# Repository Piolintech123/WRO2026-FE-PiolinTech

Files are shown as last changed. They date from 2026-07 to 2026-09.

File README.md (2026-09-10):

 <h1 align="center">Welcome to the PiolínTech Repository ꒰ঌ( •ө• )໒꒱ </h1>

<h3 align="center">
WRO Future Engineers 2026 · Panama
</h3>

<p align="center">
  PiolínTech WRO Future Engineers 2026 robot
<p align="center">
  <b>Meet Piolín — our autonomous EV3 vehicle developed for WRO Future Engineers 2026.</b>
</p>

<div align="center">

  <a href="https://youtube.com/@piolintech">
    
  </a>

  <a href="https://instagram.com/piolintech">
    
  </a>

  <a href="https://github.com/Piolintech123/WRO2026-FE-PiolinTech">
    
  </a>

</div>

<p align="center">
  
  
  
</p>

<p align="center">
  
  
  
  
  
</p>

---

## Project Summary

Piolín is the autonomous robotic vehicle developed by PiolínTech for the WRO
Future Engineers 2026 Self-Driving Car Challenge. The project is built around a
LEGO MINDSTORMS EV3 controller and a car-like vehicle architecture with rear
propulsion and Ackermann-style front steering.

Our objective is not only to make the robot complete the track. Piolín has been
developed as a complete electromechanical system in which mechanics, sensor
placement, control software, perception, testing, and calibration affect one
another. A mechanical adjustment can change sensor measurements, a sensor
relocation can require new calibration, and a software change is only useful
when the physical vehicle can reproduce the expected behavior consistently.

The current vehicle uses an EV3 Large Motor for propulsion and an EV3 Medium
Motor for steering. Two lateral EV3 Ultrasonic Sensors describe Piolín's
relationship with the track boundaries, while a downward-facing EV3 Color
Sensor detects physical Blue and Orange course landmarks. Sensor Port S1 is
round-specific: the Open Challenge uses an EV3 Gyro Sensor, while the Obstacle
Challenge uses Pixy2.1.

The current design intentionally avoids treating every available sensor as
something that must be installed at all times. The gyro and Pixy2.1 solve
different information problems, so they are used in different challenge
configurations and are not installed simultaneously.

This repository documents the complete development process behind Piolín. It
includes mechanical design, components, power distribution, sensor
architecture, autonomous software, obstacle avoidance, parking, calibration,
testing, failed ideas, engineering trade-offs, technical diagrams, 3D-printed
parts, source code, videos, photographic evidence, and the physical evolution
of the robot since 2025.

---

# General Project Index

This index is designed as the fastest path through the repository. Each section
provides direct access to the detailed documents behind the summaries in this
README, while the short descriptions explain what a judge or reader can expect
to find before opening a file.

## 1. Mobility & Mechanical Design

This section explains how Piolín moves, steers, transfers propulsion to the
rear wheels, and maintains a repeatable physical vehicle geometry. It also
documents why Ackermann steering was selected and how mechanical testing is
connected to software reliability.

- **[Mechanical Architecture](./docs/mobility_mechanical/01_mecharchitecture.md)** — Complete mechanical organization of Piolín and the relationship between the chassis, drivetrain, steering, sensors, and controller.
- **[Chassis Design](./docs/mobility_mechanical/02_chassis.md)** — Structural layout, reinforcement, packaging, physical constraints, and the reasoning behind the present chassis configuration.
- **[Robot Mobility](./docs/mobility_mechanical/03_RMobility.md)** — Vehicle movement, steering behavior, physical trajectory, and the interaction between propulsion and steering.
- **[Ackermann Steering](./docs/mobility_mechanical/04_steering.md)** — Steering geometry, steering angles, linkage behavior, mechanical limitations, and calibration.
- **[Drivetrain](./docs/mobility_mechanical/05_drivetrain.md)** — Motor A, rear propulsion, wheel transmission, mechanical coupling, and drivetrain decisions.
- **[Mechanical Testing](./docs/mobility_mechanical/06_testing.md)** — Physical testing process used to compare mechanical changes and identify repeatability problems.

<p align="center">
  <a href="./docs/mobility_mechanical/">
    
  </a>
</p>

## 2. Power & Sensor Architecture

This section explains how Piolín is powered, how every active sensor is
connected, what each sensor measures, and why the current sensor arrangement is
different between the Open and Obstacle Challenges.

- **[Power & Sensor Configuration](./docs/power_sensors/01_PowerSensorconfig.md)** — Current power and sensing architecture for both challenge configurations.
- **[Ultrasonic Sensor Design](./docs/power_sensors/02_USSensorD.md)** — The two lateral ultrasonic sensors, their physical positions, their geometric purpose, and the S2-left / S3-right convention.
- **[Color Sensor](./docs/power_sensors/03_color_sensor.md)** — S4 floor sensing, Blue and Orange detection, event confirmation, optical considerations, and calibration.
- **[Pixy2.1 Vision](./docs/power_sensors/04_pixycam.md)** — Current Pixy2.1 obstacle configuration, S1 connection, signatures, and its role in perception.
- **[Sensor Calibration](./docs/power_sensors/05_Calibration.md)** — Calibration workflow used after physical changes or environmental changes.
- **[Hardware Components](./docs/components/)** — Individual documentation for the EV3, motors, sensors, battery, power distribution, and additional parts.
- **[Technical Schemes](./schemes/README.md)** — EV3 reference, port mapping, current robot scheme, and Open configuration diagram.

<p align="center">
  <a href="./docs/power_sensors/">
    
  </a>
  <a href="./schemes/README.md">
    
  </a>
</p>

## 3. Software Architecture & Obstacle Strategy

This section contains the autonomous control logic behind Piolín. It covers
normal navigation, corner handling, color events, vision processing, obstacle
avoidance, recovery, control arbitration, software tuning, and parking.

- **[Software Architecture](./docs/software_obstacles_strategy/01_SWArchitecture.md)** — Overall software organization from sensing to final actuation.
- **[Navigation State Machine](./docs/software_obstacles_strategy/02_statemachine.md)** — How Piolín changes behavior according to its current physical situation.
- **[Wall Following & Geometry](./docs/software_obstacles_strategy/03_wallfollowing.md)** — Lateral navigation using the left and right Ultrasonic Sensors.
- **[Corner Handling](./docs/software_obstacles_strategy/04_cornerhandling.md)** — Why corners are handled differently from straight sections and how physical evidence is used.
- **[Obstacle Detection](./docs/software_obstacles_strategy/05_obstacledetec.md)** — How vision detections are validated and filtered before changing the robot trajectory.
- **[Obstacle Strategy](./docs/software_obstacles_strategy/06_obstaclestrateg.md)** — Red-right, Green-left passing behavior, target lifecycle, pass confirmation, and recovery.
- **[Software Tuning](./docs/software_obstacles_strategy/07_softwaretuning.md)** — How controller values and behaviors are adjusted through real track testing.
- **[Pixy Vision Processing](./docs/software_obstacles_strategy/08_CameraPXVision.md)** — Interpretation of signature, x, y, width, height, candidate relevance, and target selection.
- **[RGB Detection](./docs/software_obstacles_strategy/09_RGBdetection.md)** — Color classification logic used for floor sensing and experimental detection work.
- **[Color & Lap Counting](./docs/software_obstacles_strategy/10_color_and_lap_counting.md)** — Physical event processing, duplicate prevention, course progress, and lap counting.

### Parking Documentation

Parking is documented separately because it is a complete navigation problem
rather than a final timing command.

- **[Parking Overview](./docs/software_obstacles_strategy/parking/01_ParkingOverview.md)** — Complete parking objective and the information available to the robot.
- **[Parking Algorithm](./docs/software_obstacles_strategy/parking/02_ParkingAlgorithm.md)** — Approach, entry, alignment, final position, and stopping logic.
- **[Parking Geometry](./docs/software_obstacles_strategy/parking/03_ParkingGeom.md)** — Relationship between vehicle geometry and the physical parking maneuver.
- **[Parking Calibration](./docs/software_obstacles_strategy/parking/04_ParkingCalib.md)** — Parameters that must be validated on the real robot.
- **[Parking Testing](./docs/software_obstacles_strategy/parking/05_Parkingtesting.md)** — Repeatability tests and failure analysis for the parking maneuver.

### Published Source Code

- **[Round 1 — Open Code](./code/round1/ev3v1.py)** — Published Open Challenge EV3 program.
- **[Round 1 Code Explanation](./code/round1/r1_exp.md)** — Detailed explanation of the Round 1 program, its logic, and its limitations.
- **[Round 2 — Obstacle Code](./code/round2/ev3v1.py)** — Published Obstacle Challenge EV3 program.
- **[Round 2 Code Explanation](./code/round2/r2_exp.md)** — Detailed explanation of the Pixy2.1, ultrasonic, obstacle, and steering logic used in the published Round 2 version.

<p align="center">
  <a href="./docs/software_obstacles_strategy/">
    
  </a>
  <a href="./code/">
    
  </a>
</p>

## 4. Systems Thinking & Engineering Decisions

This section explains why the current robot looks and behaves the way it does.
It records alternatives, trade-offs, failure modes, risk analysis, design
constraints, and the engineering process used to decide whether a change should
remain in the robot.

- **[Engineering Process](./docs/systems_engineering/01_engineeringprocess.md)** — Observe, identify the first incorrect behavior, form a hypothesis, change one variable, test, compare, and document.
- **[Decision Log](./docs/systems_engineering/02_decisionlog.md)** — Major mechanical, sensing, and software decisions with their reasoning.
- **[Design Constraints](./docs/systems_engineering/03_designconstraints.md)** — Competition, mechanical, sensor, control, and practical constraints.
- **[Trade-offs](./docs/systems_engineering/04_tradeoffs.md)** — Comparison of alternative approaches and the reasons behind current choices.
- **[Risks & Mitigation](./docs/systems_engineering/05_risksandmitigation.md)** — Important failure conditions and how the design attempts to reduce their impact.
- **[What Didn't Work](./docs/systems_engineering/06_whatdidntwork.md)** — Rejected ideas, failed experiments, and lessons that affected later versions.
- **[Project Timeline](./t-gtku/timeline.md)** — Development history beginning in June 2025.
- **[Robot Evolution](./models/evolution/Phase1.md)** — Entry point to the documented physical and architectural evolution of Piolín.

<p align="center">
  <a href="./docs/systems_engineering/">
    
  </a>
  <a href="./t-gtku/timeline.md">
    
  </a>
</p>

## 5. Reproducibility & GitHub Quality

This section contains the information required to understand how Piolín is
assembled, wired, configured, calibrated, programmed, tested, and diagnosed.

- **[Reproducibility Overview](./docs/reproducibility/01_ReproducibilityOverview.md)** — Starting point for reproducing the present hardware and software configuration.
- **[Bill of Materials](./docs/reproducibility/02_BOM.pdf)** — Components required for the robot.
- **[Wiring Guide](./docs/reproducibility/03_wiring.md)** — Motor, sensor, and round-specific S1 connections.
- **[Electrical Schematics](./docs/reproducibility/04_elecschem.md)** — Electrical and port-reference diagrams.
- **[Software Setup](./docs/reproducibility/05_softwaresetup.md)** — Preparing the EV3 environment and transferring the competition programs.
- **[Calibration Guide](./docs/reproducibility/06_HowToCalibrate.md)** — Steering, ultrasonic, color, gyro, and Pixy calibration.
- **[Testing Protocol](./docs/reproducibility/07_TestingProtocol.md)** — How tests are repeated and compared.
- **[Troubleshooting](./docs/reproducibility/08_Troubleshooting.md)** — Diagnosing common mechanical, sensing, and software problems.
- **[3D Printing Files](./models/3dprint/)** — STL files and manufacturing documentation.
- **[Vehicle Photo Archive](./v-photos/README.md)** — Visual evidence of the robot from previous generations through V4.
- **[Videos](./videos/links.md)** — Autonomous track demonstrations and test footage.

<p align="center">
  <a href="./docs/reproducibility/">
    
  </a>
  <a href="./docs/reproducibility/02_BOM.pdf">
    
  </a>
</p>

---

# Watch Piolín

## Video Evidence

The fastest way to understand Piolín is to see the vehicle operating on the
physical track. Our videos provide direct evidence of autonomous behavior under
both competition configurations and complement the source code and technical
documents stored in this repository.

The Open Challenge demonstration shows Piolín operating with the Open-round
sensing configuration. The Obstacle Challenge demonstration shows the vehicle
operating with visual traffic-sign detection and obstacle navigation.

<p align="center">
  <a href="https://www.youtube.com/watch?v=JROB39Az-Ys">
    
  </a>
  <a href="https://youtu.be/Tlw_LM0b6WE">
    
  </a>
</p>

Additional demonstrations and testing material are available in
[videos/links.md](./videos/links.md).

---

# Meet the Team

## Team Overview

We are PiolínTech, a robotics team from Colegio Bilingüe de Panamá. Developing
Piolín has required collaboration across mechanical construction, programming,
sensor calibration, testing, documentation, failure analysis, and redesign.

Future Engineers has repeatedly shown us that many problems cannot be separated
into purely mechanical or purely software categories. A steering error may
originate from code, but it can also result from linkage geometry or mechanical
alignment. A sensor problem may originate from software thresholds, but it may
also come from mounting geometry, light conditions, or the surface being
observed.

For that reason, the team approaches Piolín as a complete system. The objective
during testing is not only to make the visible symptom disappear, but to
understand which subsystem caused the first incorrect behavior.

| Member | Information | Contact |
| :---: | :--- | :---: |
|  | **Sebastián Martínez**<br>Colegio Bilingüe de Panamá | [Instagram](https://www.instagram.com/sebastian.mvrl/) |
|  | **Mia Cantoral**<br>Colegio Bilingüe de Panamá | [Instagram](https://www.instagram.com/miaacnt) |
|  | **Christian Castrellón**<br>Colegio Bilingüe de Panamá | [Instagram](https://www.instagram.com/cj.chriss) |
| **Coach** | **Hanna Figueroa**<br>Colegio Bilingüe de Panamá | |

<p align="center">
  <a href="./t-gtku/officialpictureptech.md">
    
  </a>
  <a href="./t-gtku/funnypicture.md">
    
  </a>
  <a href="./t-gtku/timeline.md">
    
  </a>
</p>

---

# Meet Piolín

## Current Vehicle Overview

<p align="center">
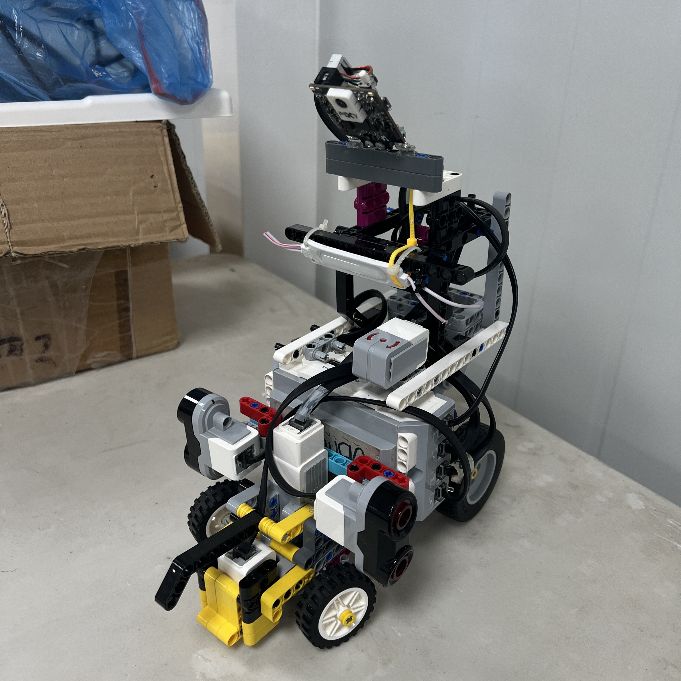
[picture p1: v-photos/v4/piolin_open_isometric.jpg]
Current Piolín V4 robot
  
</p>

The current V4 Piolín architecture is built around clearly defined subsystem
responsibilities. Motor A handles propulsion, Motor B controls Ackermann
steering, S2 and S3 observe lateral track geometry, and S4 detects physical
floor landmarks.

S1 is the only major sensor port that changes between challenges. During the
Open Challenge, S1 contains the EV3 Gyro Sensor. During the Obstacle Challenge,
the gyro is removed and Pixy2.1 is installed instead.

Piolín currently has a measured mass of 0.84 kg. Current practical physical
references are approximately 250 mm in overall length, approximately 119 mm
across the front assembly, approximately 105 mm across the rear assembly,
approximately 290 mm in height, and approximately 120 mm between the axles.

These physical references are treated as current measurements rather than
permanent CAD values. Mechanical changes can alter the final configuration, so
the robot is rechecked when a modification affects the competition envelope,
sensor location, or steering geometry.

## Current Hardware

| System | Current Configuration |
| --- | --- |
| **Controller** | LEGO MINDSTORMS EV3 |
| **Propulsion** | EV3 Large Motor — Port A |
| **Steering** | EV3 Medium Motor — Port B |
| **Steering Geometry** | Ackermann-style |
| **Drive Layout** | Rear propulsion |
| **Left Distance Sensor** | EV3 Ultrasonic — S2 |
| **Right Distance Sensor** | EV3 Ultrasonic — S3 |
| **Floor Sensor** | EV3 Color Sensor — S4 |
| **Open S1 Device** | EV3 Gyro Sensor |
| **Obstacle S1 Device** | Pixy2.1 |
| **Battery** | EV3 Rechargeable Battery 45501 |
| **Measured Mass** | **0.84 kg** |

---

## Two Challenges, One Core Platform

Piolín uses the same core mechanical vehicle for both competition challenges.
Keeping the drivetrain, steering system, controller, two lateral Ultrasonic
Sensors, and Color Sensor consistent reduces the number of variables that
change when moving from one challenge to the other.

The main round-specific difference is S1. During Open, Piolín needs independent
heading and rotation information, so the EV3 Gyro Sensor occupies S1. During
Obstacles, visual color-signature information is required, so the gyro is
removed and Pixy2.1 takes its place.

The gyro and Pixy2.1 are not installed simultaneously in the current
competition architecture.

| Port | Open Challenge | Obstacle Challenge |
| :---: | --- | --- |
| **A** | EV3 Large Motor — propulsion | EV3 Large Motor — propulsion |
| **B** | EV3 Medium Motor — steering | EV3 Medium Motor — steering |
| **S1** | EV3 Gyro Sensor | Pixy2.1 |
| **S2** | LEFT Ultrasonic Sensor | LEFT Ultrasonic Sensor |
| **S3** | RIGHT Ultrasonic Sensor | RIGHT Ultrasonic Sensor |
| **S4** | Downward Color Sensor | Downward Color Sensor |

<p align="center">
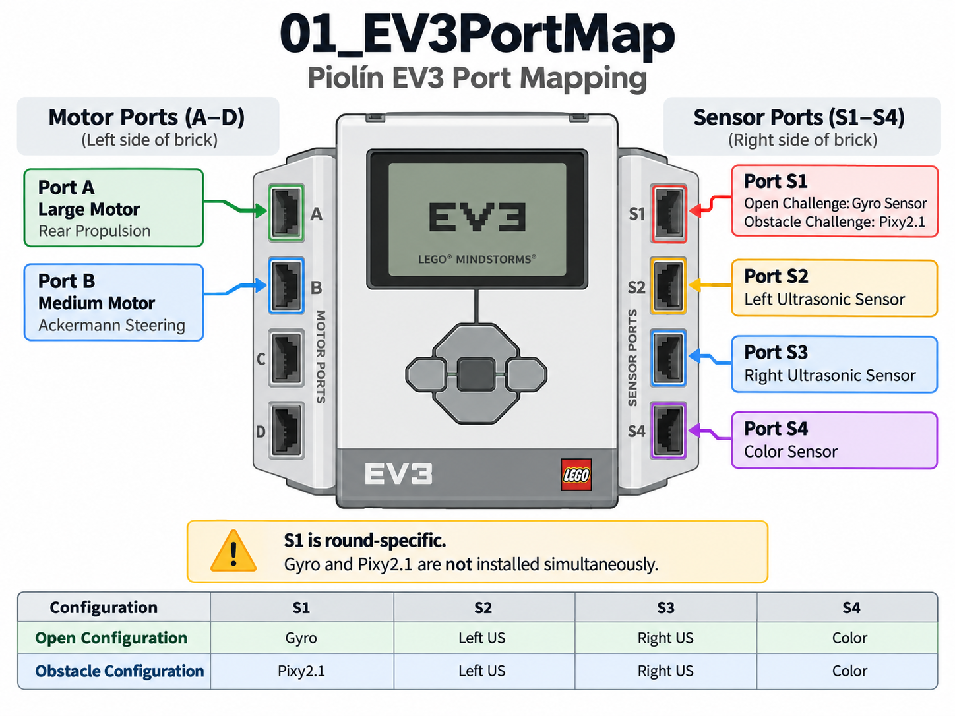
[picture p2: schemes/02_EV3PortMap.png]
Piolín EV3 Port Map
  
</p>

S2 remains physically left and S3 remains physically right in both rounds.
Their interpretation as an inner or outer sensor changes only according to the
course direction.

---

# Mobility & Mechanical Design

## Mechanical Overview

<p align="center">
  
</p>

Piolín uses a car-like architecture based on rear propulsion and
Ackermann-style front steering. Motor A drives the rear section of the vehicle,
while Motor B controls the steering mechanism at the front.

Unlike a differential-drive robot, Piolín cannot simply rotate by driving the
left and right sides at different speeds. Its path depends on the steering
angle of the front wheels and the forward or reverse motion generated by the
drivetrain.

This makes mechanical geometry part of the control problem. A different
steering angle, linkage position, wheel alignment, or chassis flex can change
the path produced by exactly the same software command.

The mechanical documentation therefore focuses not only on what pieces are
present, but also on how the physical arrangement affects autonomous behavior.

<p align="center">
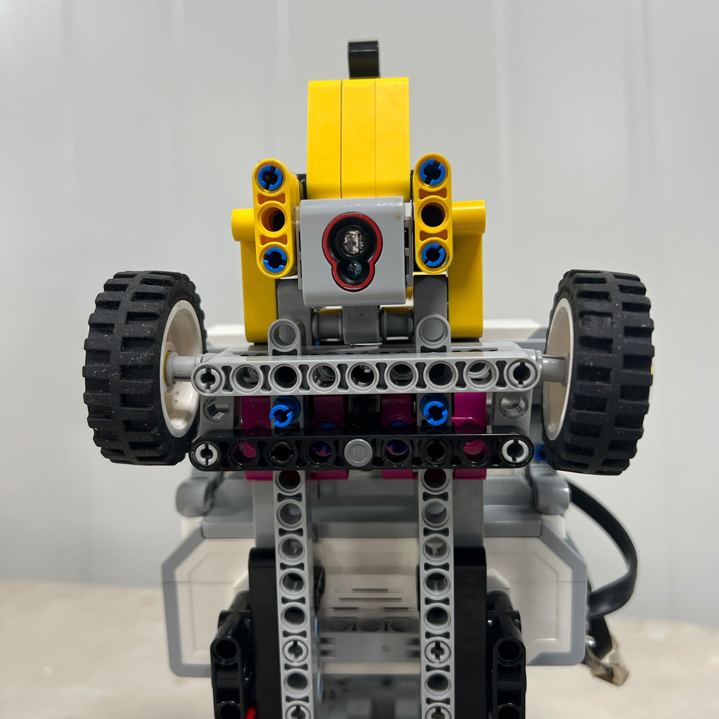
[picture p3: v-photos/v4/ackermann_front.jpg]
Piolín Ackermann steering
  
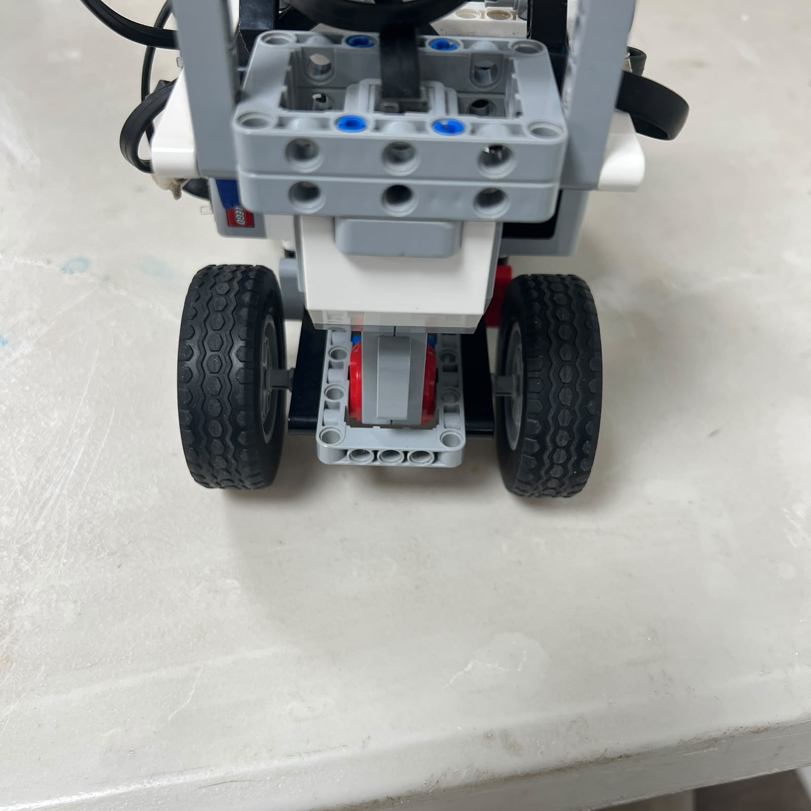
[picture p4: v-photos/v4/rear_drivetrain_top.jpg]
Piolín rear drivetrain
  
</p>

## Ackermann Steering

During a turn, the inner front wheel follows a smaller radius than the outer
front wheel. The two wheels should therefore not remain perfectly parallel
throughout the maneuver.

Ackermann steering provides a geometric relationship between the inner and
outer wheel angles so the wheel paths converge toward a common turning center.

The ideal relationship can be represented by:

$$
\cot(\delta_{outer})-\cot(\delta_{inner})=\frac{w}{L}
$$

where \(w\) represents the track width and \(L\) represents the wheelbase.

The equation provides a useful geometric model, but the real LEGO mechanism
still has physical tolerances. Joint clearance, tire deformation, steering
linkage geometry, Motor B positioning, mechanical stops, and assembly alignment
influence the actual vehicle trajectory.

For that reason, steering geometry is evaluated through photographs, angle
observations, repeated runs, and physical calibration rather than assuming that
the theoretical model alone predicts the complete motion.

<p align="center">
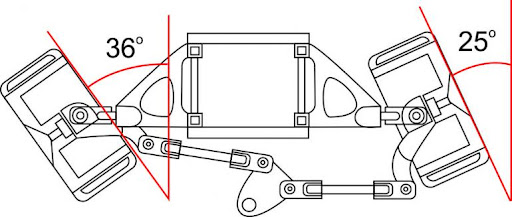
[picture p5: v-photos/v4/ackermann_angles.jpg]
Ackermann steering analysis
  
</p>

## Steering Motor

The EV3 Medium Motor on Port B is dedicated to steering. Using a separate motor
for the steering system allows the software to reason about vehicle speed and
steering angle as different control variables.

The steering motor is centered before autonomous testing so its encoder
reference corresponds as closely as possible to the straight-wheel position.

A steering command is useful only when the mechanical linkage responds
consistently. If the linkage is loose, asymmetric, or physically obstructed, a
correct Motor B target can still produce an incorrect path.

This is why steering calibration always has both a software and mechanical
component.

<p align="center">
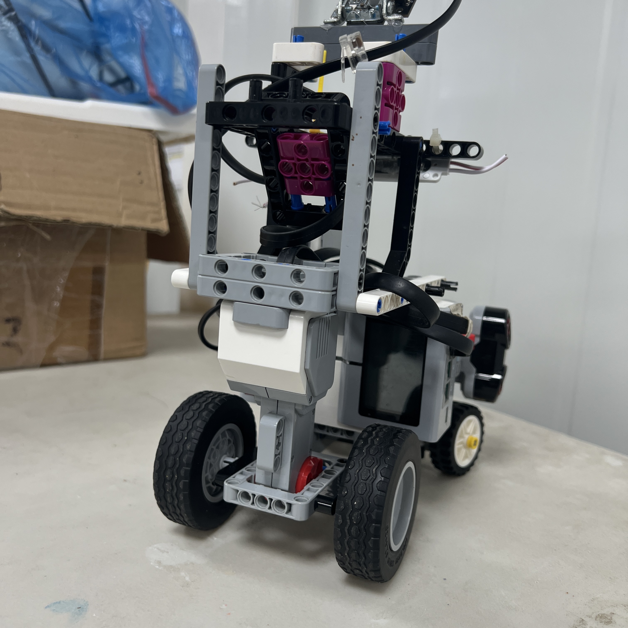
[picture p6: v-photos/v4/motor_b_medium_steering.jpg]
Motor B steering
  
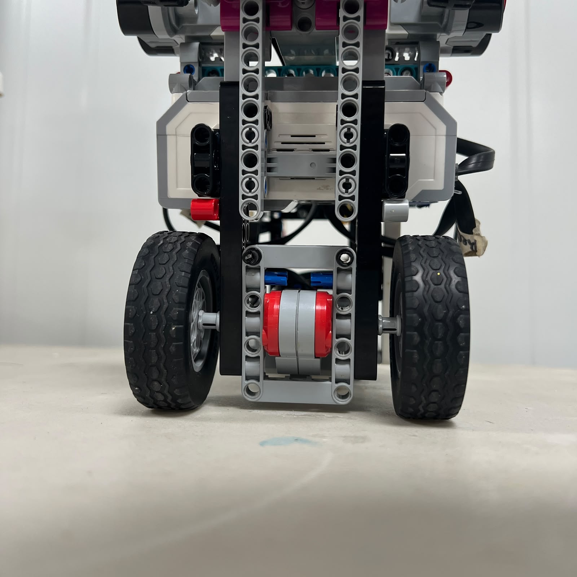
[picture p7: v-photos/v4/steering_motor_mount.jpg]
Steering motor mount
  
</p>

## Chassis Development

Piolín's chassis has changed repeatedly throughout development. Early versions
were useful for discovering how much space was required for the EV3, steering
mechanism, drivetrain, sensors, wiring, and later the vision system.

As the project matured, the chassis became more strongly connected to
navigation performance. A structural element that moves under load can affect
steering. A sensor mount that rotates slightly can change distance
measurements. A cable that interferes with steering can cause a software
symptom even though the controller is functioning correctly.

The current chassis therefore aims to maintain repeatable positions for the
main mechanical and sensing components while still remaining practical to
service and recalibrate.

The repository preserves previous versions because the transition from those
layouts to V4 provides evidence of the engineering process.

<p align="center">
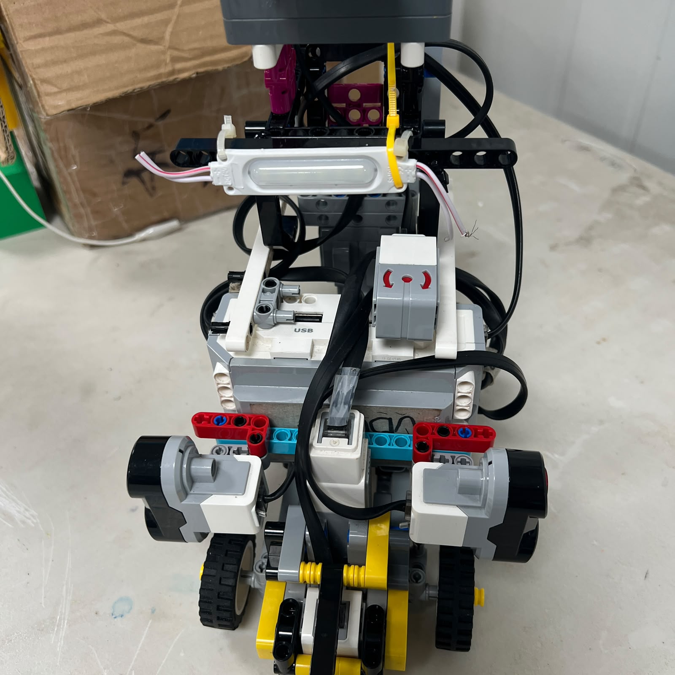
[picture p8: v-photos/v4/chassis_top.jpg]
Current chassis top view
  
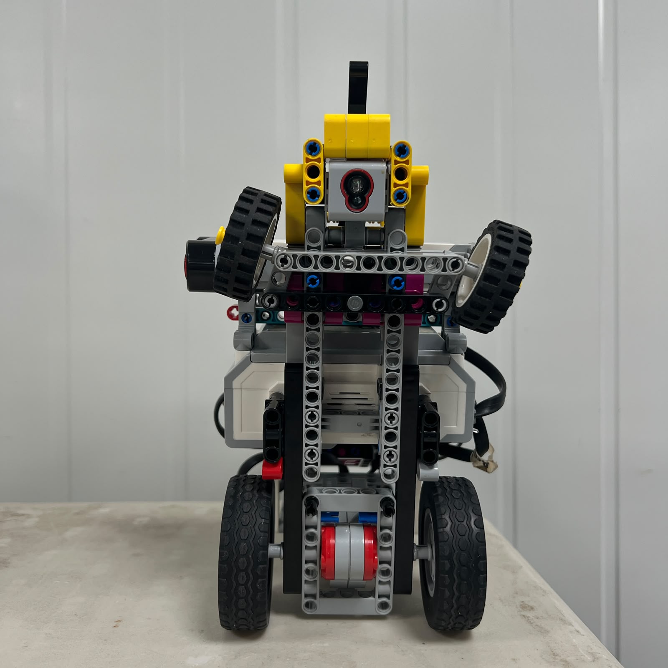
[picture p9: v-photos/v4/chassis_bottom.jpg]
Current chassis bottom view
  
</p>

## Rear Drivetrain

Motor A is an EV3 Large Motor dedicated to propulsion. Its role is mechanically
separate from Motor B, which means steering changes do not require differential
motor-speed control.

Keeping propulsion inside the EV3 ecosystem reduces wiring complexity and gives
the controller direct access to encoder information from the drive motor.

The drivetrain is evaluated as a complete path from motor output to wheel
motion. Mechanical losses, wheel grip, structural alignment, and the physical
load on the robot all influence how the vehicle accelerates and how
consistently it follows a requested path.

<p align="center">
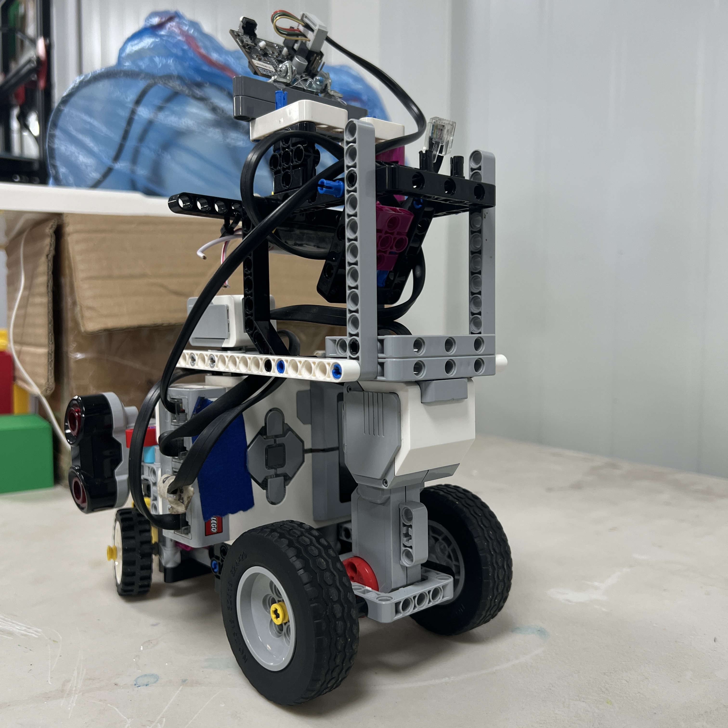
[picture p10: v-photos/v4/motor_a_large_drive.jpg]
EV3 Large Motor
  
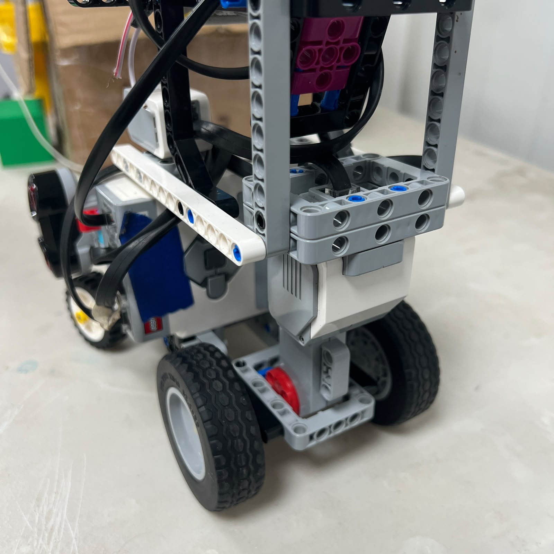
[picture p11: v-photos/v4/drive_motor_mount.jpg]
Drive motor mounting
  
</p>

## Torque and Dynamic Reasoning

Piolín currently has a measured mass of 0.84 kg. The drivetrain therefore has
to move the complete robot mass while overcoming rolling resistance and any
additional losses caused by wheel contact and drivetrain friction.

A simplified longitudinal force requirement can be represented as:

$$
F_t = ma + F_{resistance}
$$

and the corresponding wheel torque as:

$$
\tau = F_t r
$$

where \(m\) is vehicle mass, \(a\) is acceleration, \(F_{resistance}\)
represents resistive forces, and \(r\) is the effective radius of the driven
wheel.

These equations are used as engineering references rather than as claims of
guaranteed performance. Real track behavior depends on friction, tire
deformation, battery state, wheel alignment, and mechanical losses that are
difficult to represent perfectly in a simplified model.

<p align="center">
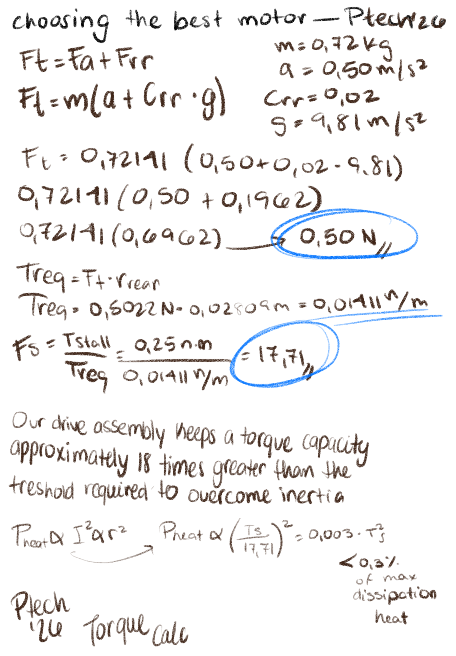
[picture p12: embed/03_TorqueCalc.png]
Piolín torque calculation
  
</p>

## Mechanical Testing Philosophy

Mechanical testing is performed with the same mindset used for software
testing. We try to isolate the first physical behavior that changes when a run
becomes unreliable.

If Piolín begins to drift, the first question is not automatically which
controller value should be changed. The team checks wheel alignment, steering
centering, sensor position, mechanical interference, and the condition of the
drivetrain before assuming that the problem originates in code.

This avoids compensating for a mechanical fault with increasingly aggressive
software corrections.

<p align="center">
  <a href="./docs/mobility_mechanical/01_mecharchitecture.md">
    
  </a>
  <a href="./docs/mobility_mechanical/04_steering.md">
    
  </a>
  <a href="./docs/mobility_mechanical/05_drivetrain.md">
    
  </a>
  <a href="./docs/mobility_mechanical/06_testing.md">
    
  </a>
</p>

---

# Power & Sensor Architecture

## Electrical and Sensing Overview

<p align="center">
  
</p>

Piolín is powered by the official LEGO MINDSTORMS EV3 Rechargeable DC Battery
45501. The EV3 Brick is the central controller and also provides the interfaces
used by the motors and active sensors.

The current competition architecture intentionally avoids unnecessary external
power and control layers. There is no Raspberry Pi, external propulsion
battery, custom H-bridge, or Arduino Nano in the current configuration.

Earlier experiments with additional electronics remain documented in the legacy
section because they influenced later engineering decisions, especially the
preference for simpler communication paths and fewer failure points.

<p align="center">
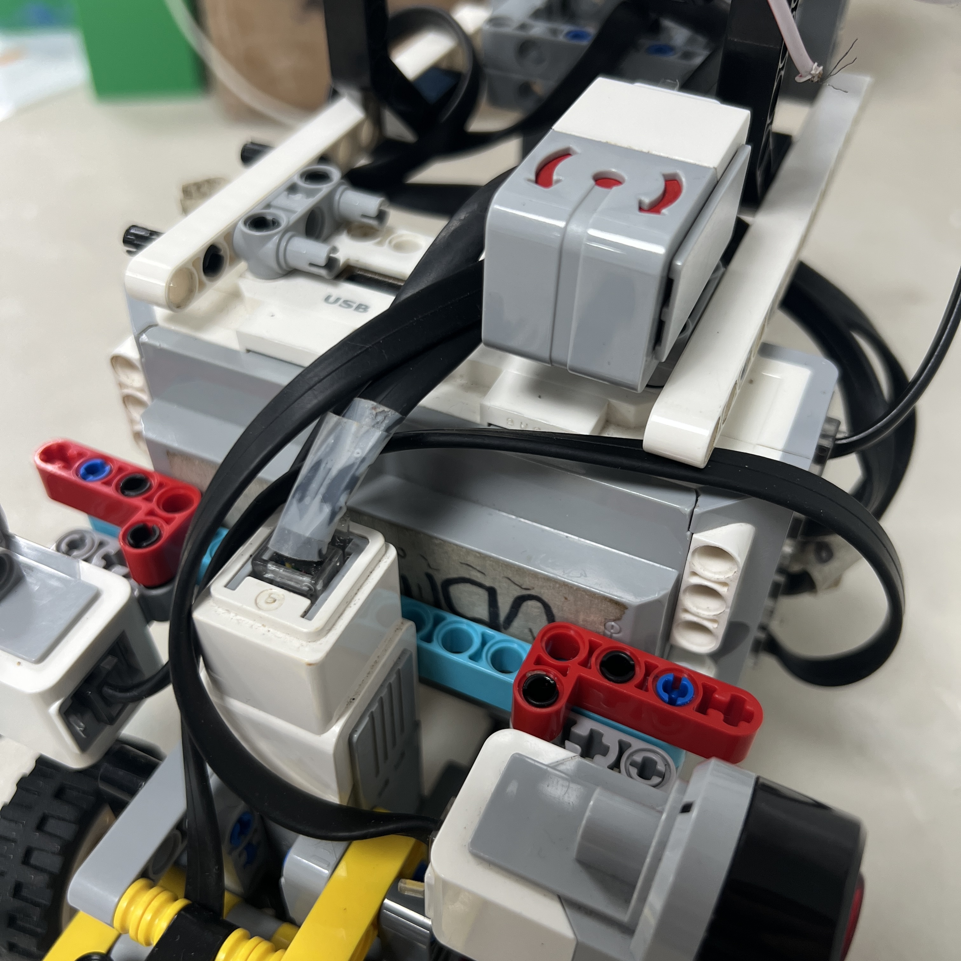
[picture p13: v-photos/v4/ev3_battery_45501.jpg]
EV3 Rechargeable Battery 45501
  
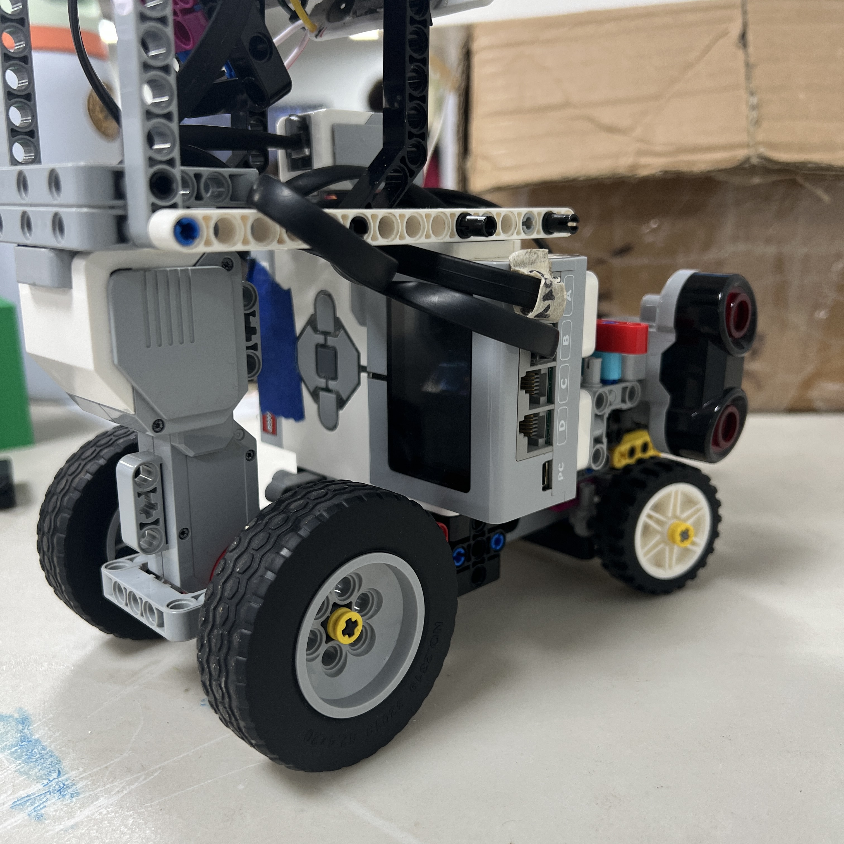
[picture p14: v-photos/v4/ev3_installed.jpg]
EV3 installed in Piolín
  
</p>

## EV3 Controller

The EV3 Brick is the central control unit in every current Piolín
configuration. It executes the navigation software, reads sensors, commands the
two motors, and provides the physical port structure that keeps the electrical
architecture organized.

The decision to remain centered around EV3 also improves reproducibility. The
motors, gyro, ultrasonic sensors, Color Sensor, and battery are all directly
associated with the same platform.

Pixy2.1 is the principal non-LEGO sensing device in the current obstacle
configuration.

<p align="center">
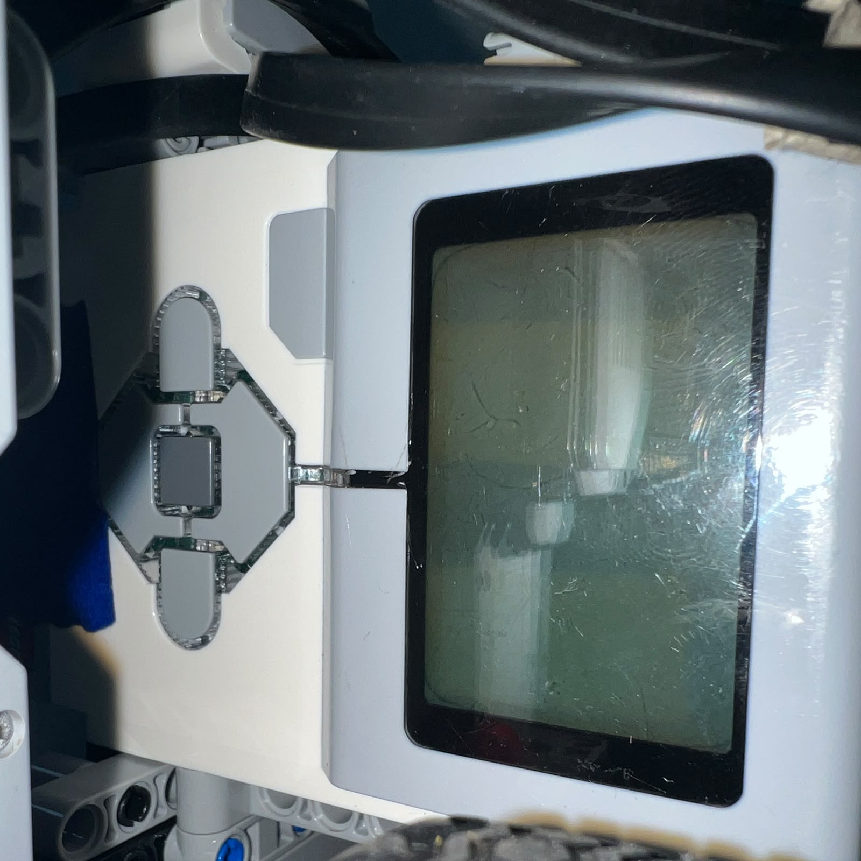
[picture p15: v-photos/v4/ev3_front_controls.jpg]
EV3 front controls
  
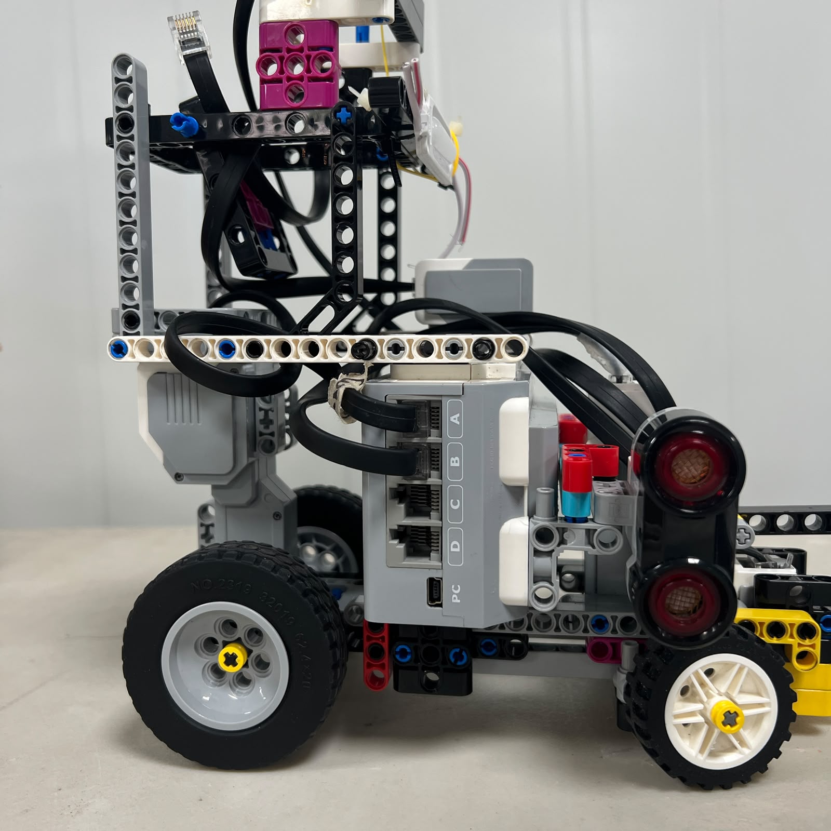
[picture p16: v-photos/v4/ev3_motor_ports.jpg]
EV3 motor ports
  
</p>

## Lateral Ultrasonic Sensors

Piolín uses two EV3 Ultrasonic Sensors mounted laterally. S2 is physically
installed on the left side of the robot and S3 is physically installed on the
right.

Their role is broader than detecting whether a wall exists. The distances help
describe the geometry around the vehicle and provide information that can be
used for lateral positioning, wall safety, corner reacquisition, and obstacle
recovery.

Because ultrasonic readings depend strongly on the surface being observed and
the angle between the sensor and that surface, sensor mounting is treated as
part of calibration.

Changing the orientation of one sensor can alter the apparent course geometry
without changing the actual robot position.

<p align="center">
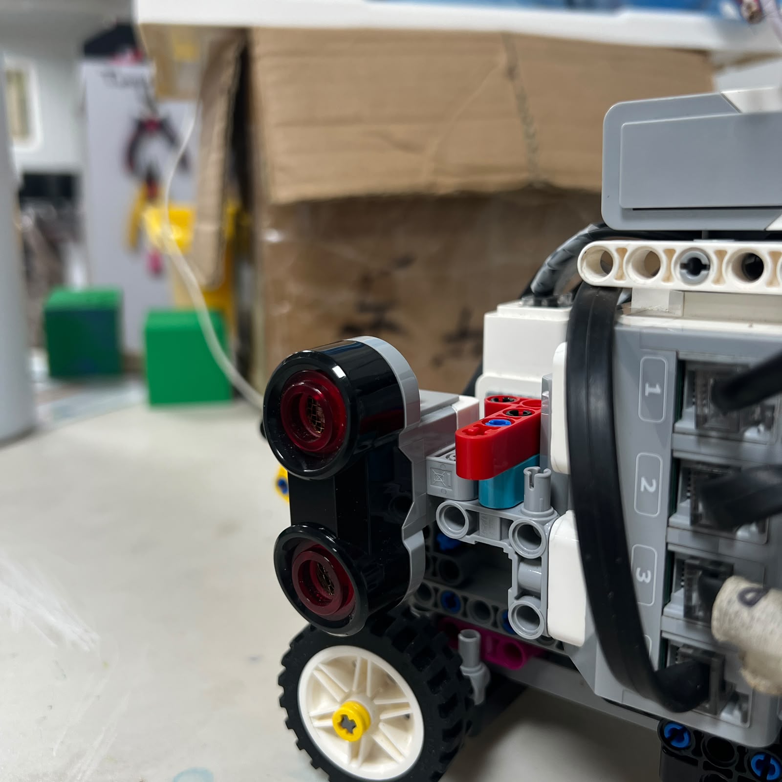
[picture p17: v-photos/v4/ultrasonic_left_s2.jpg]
Left ultrasonic sensor S2
  
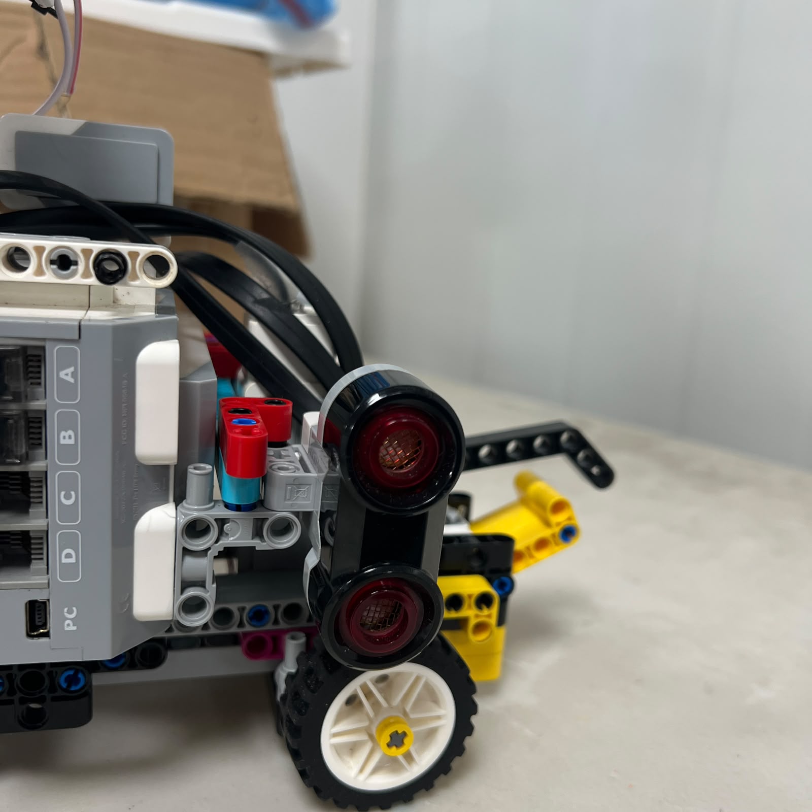
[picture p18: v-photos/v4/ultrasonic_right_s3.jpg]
Right ultrasonic sensor S3
  
</p>

## Ultrasonic Geometry

During straight navigation, the two side sensors provide complementary
information. When the robot is positioned near a wall, one sensor may describe
the nearer side more directly while the other provides context about the
surrounding corridor.

During a corner, those measurements change because the sensors begin observing
different surfaces or different angles of the same boundary.

This is why the software does not treat every sudden distance change as a
lateral error. Course state and heading context matter.

<p align="center">
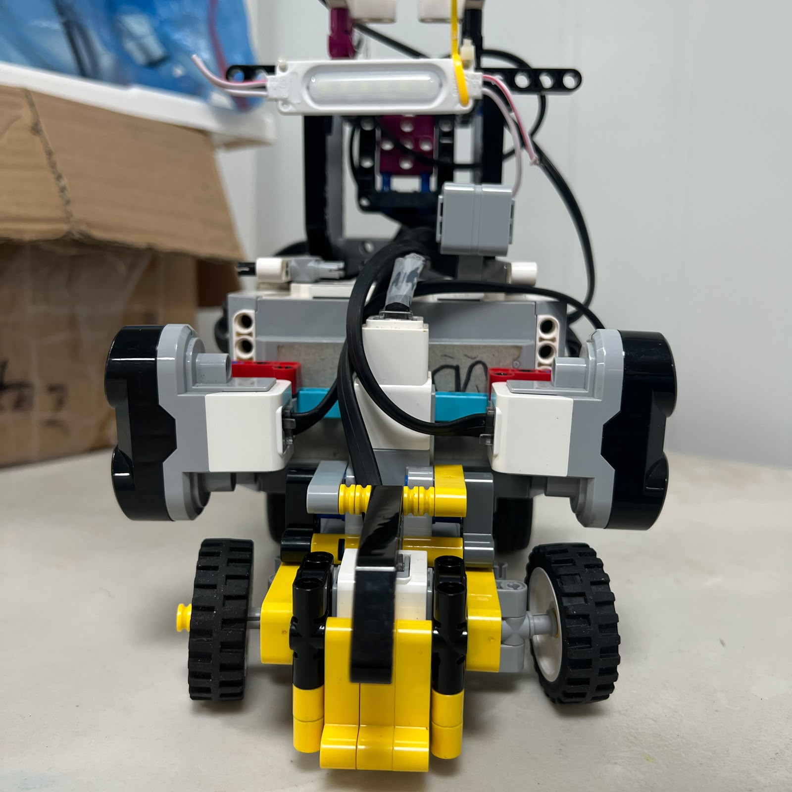
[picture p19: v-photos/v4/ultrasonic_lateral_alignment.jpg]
Ultrasonic lateral alignment
  
</p>

## Color Sensor

The EV3 Color Sensor on S4 is mounted facing downward. Its purpose is to detect
important floor markings and convert them into physical navigation events.

Blue and Orange markings are used to determine initial driving direction and
contribute to course progression.

A custom 3D-printed casing surrounds the sensor to create a more controlled
local optical environment. The casing can reduce the effect of uncontrolled
light entering from the sides, but it does not make the Color Sensor immune to
environmental variation.

For that reason, the software still uses classification, confirmation, event
latching, and neutral-floor release.

<p align="center">
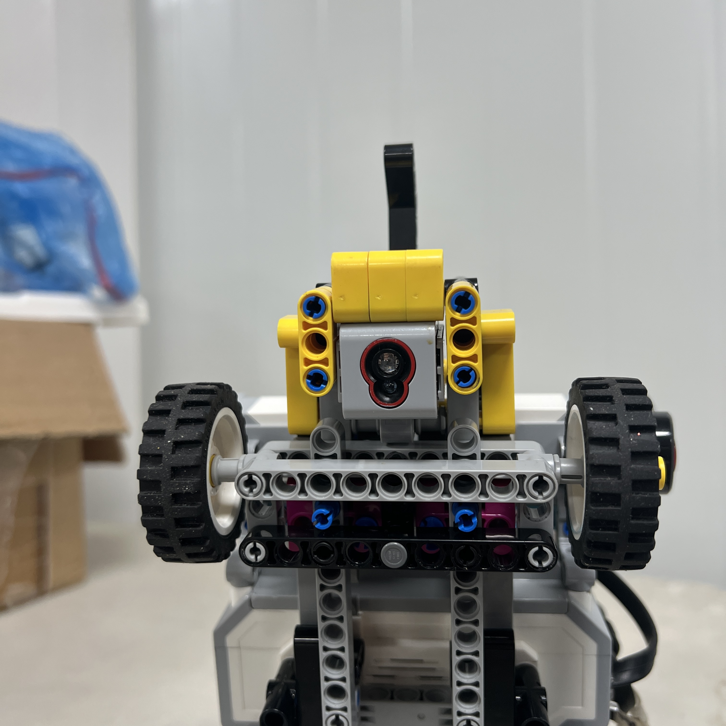
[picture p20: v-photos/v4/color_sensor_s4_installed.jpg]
S4 Color Sensor installed
  
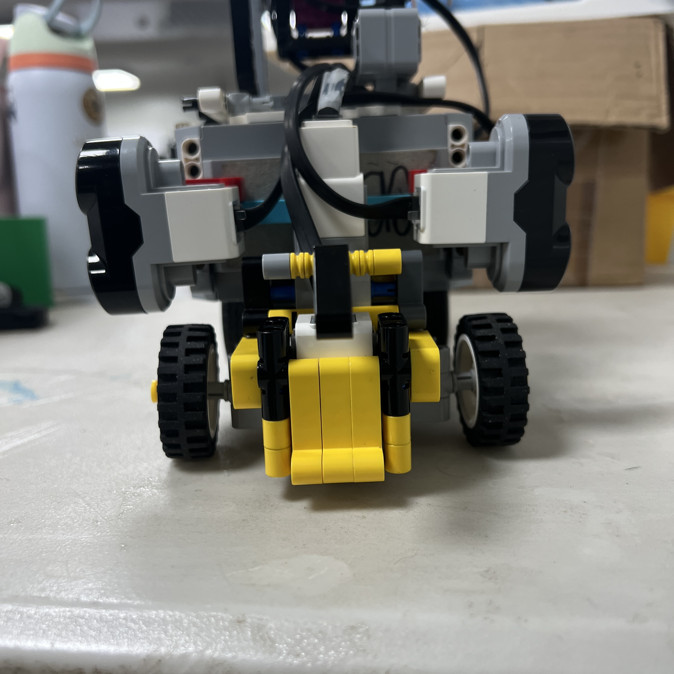
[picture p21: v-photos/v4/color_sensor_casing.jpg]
Color Sensor casing
  
</p>

<p align="center">
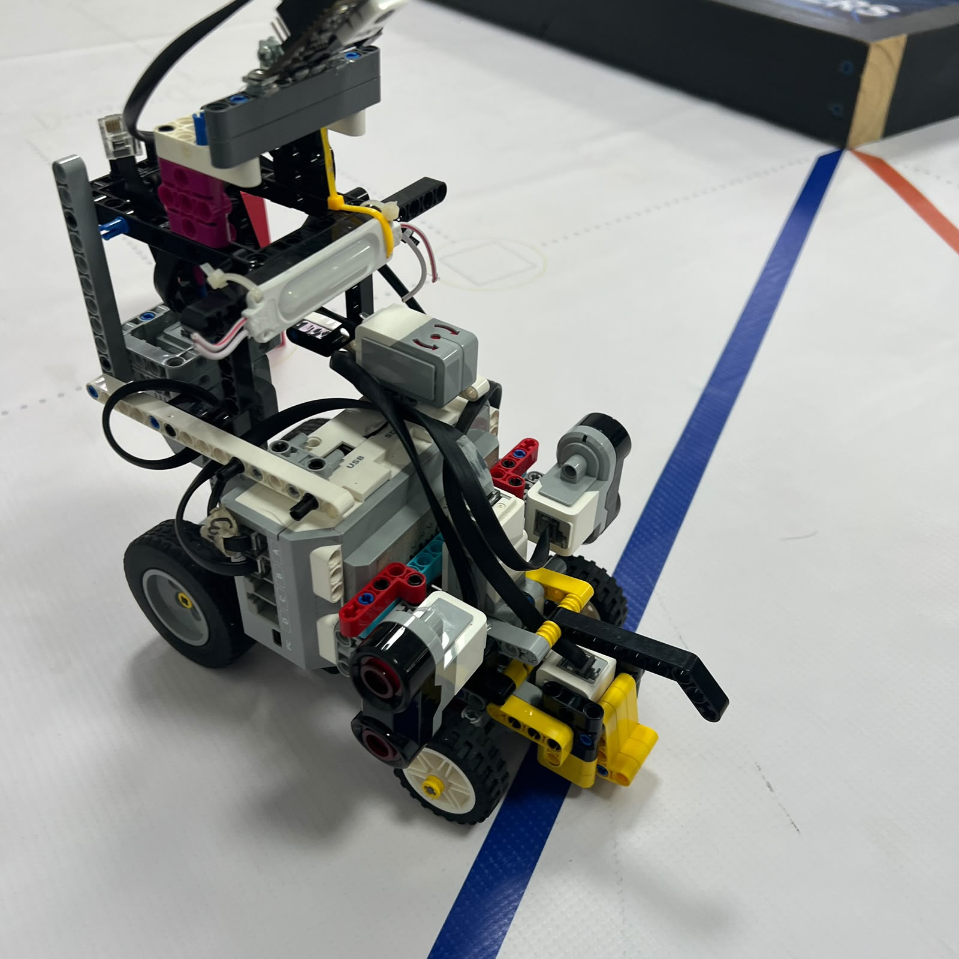
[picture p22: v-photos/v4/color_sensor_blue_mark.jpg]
Blue mark
  
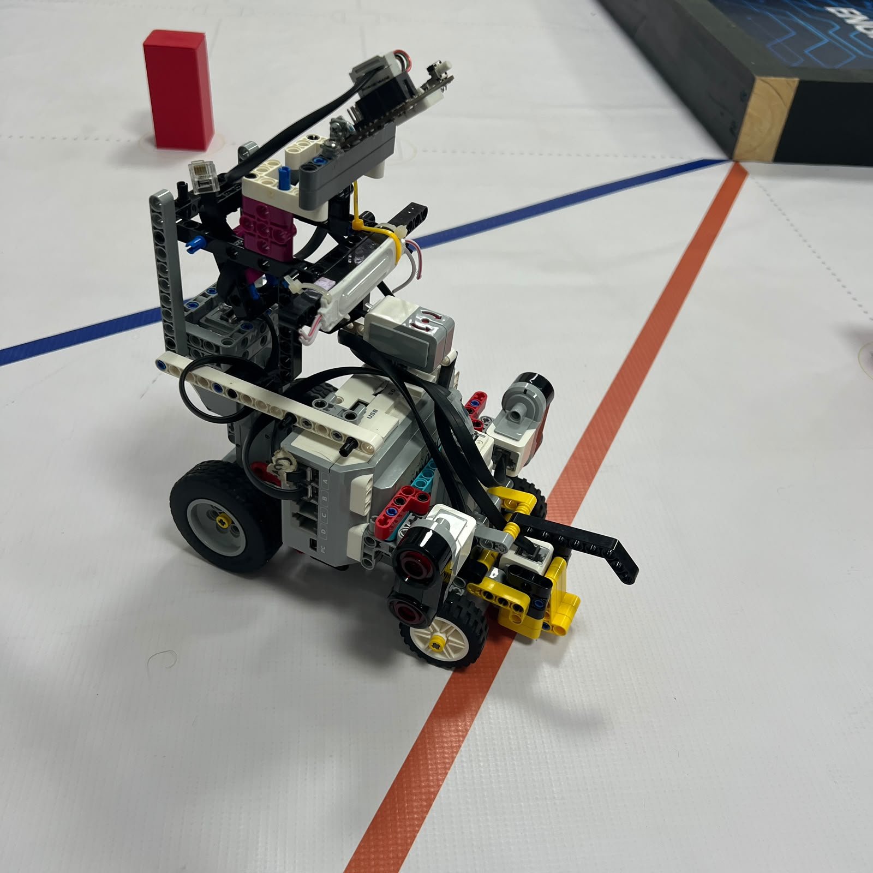
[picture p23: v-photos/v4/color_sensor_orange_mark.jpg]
Orange mark
  
</p>

## Gyro — Open Configuration

During the Open Challenge, an EV3 Gyro Sensor occupies S1. The gyro provides
heading and rotational information that complements the lateral Ultrasonic
Sensors.

This becomes especially useful during cornering. The Ultrasonic Sensors change
what they observe while the robot rotates, so they cannot always be interpreted
in the same way as during a straight section.

The gyro provides a separate indication of how the chassis is turning, helping
the software reason about corner progression and heading stabilization.

<p align="center">
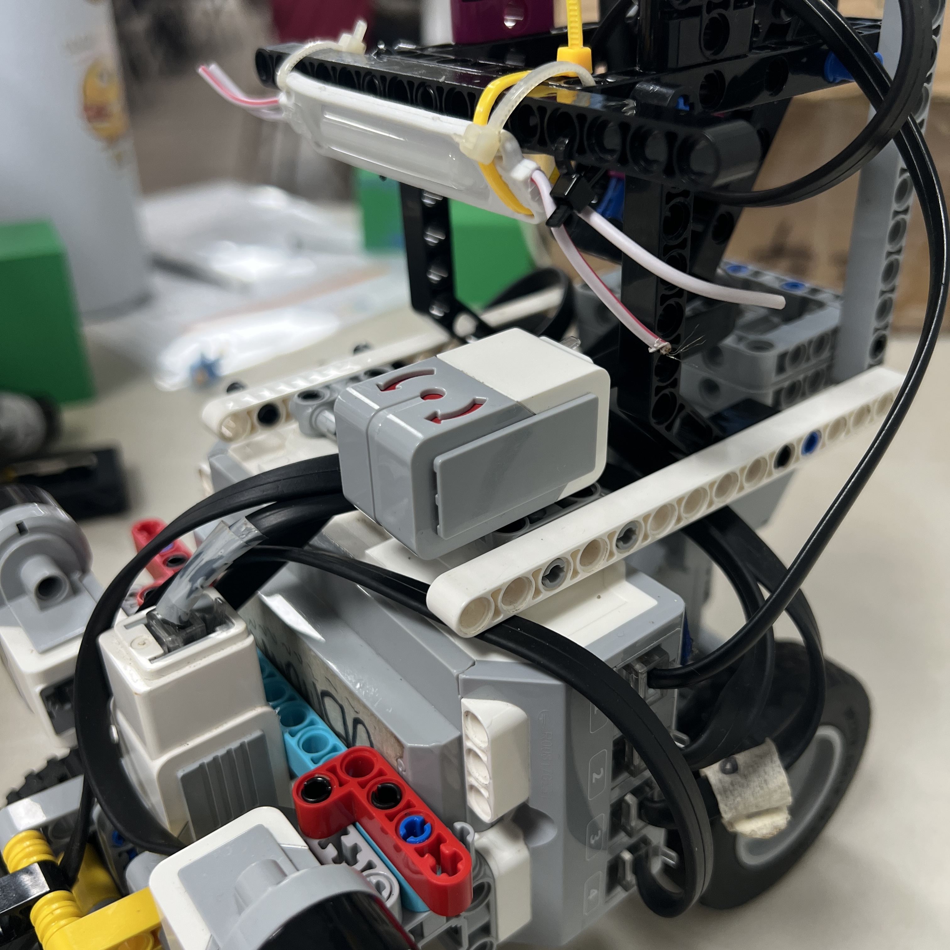
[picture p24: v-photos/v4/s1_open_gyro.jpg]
Gyro on S1
  
</p>

## Pixy2.1 — Obstacle Configuration

During the Obstacle Challenge, the gyro is removed and Pixy2.1 occupies S1.

Pixy2.1 performs onboard color-signature detection and reports block
information such as signature, horizontal position, vertical position, width,
and height to the EV3.

The camera provides perception data, but it does not directly decide the
steering direction. The EV3 software interprets the camera output according to
the competition rule and current navigation state.

The current signature convention is Pink for parking, Red for a Red pillar, and
Green for a Green pillar.

<p align="center">
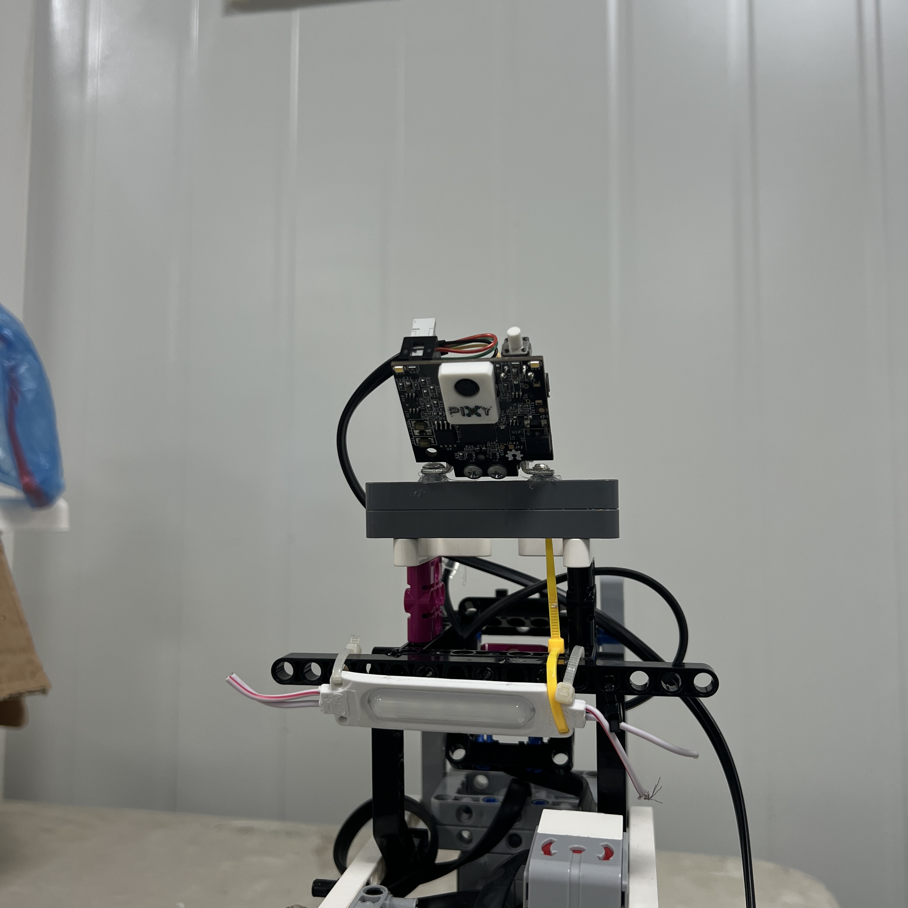
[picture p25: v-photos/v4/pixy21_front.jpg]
Pixy2.1 front view
  
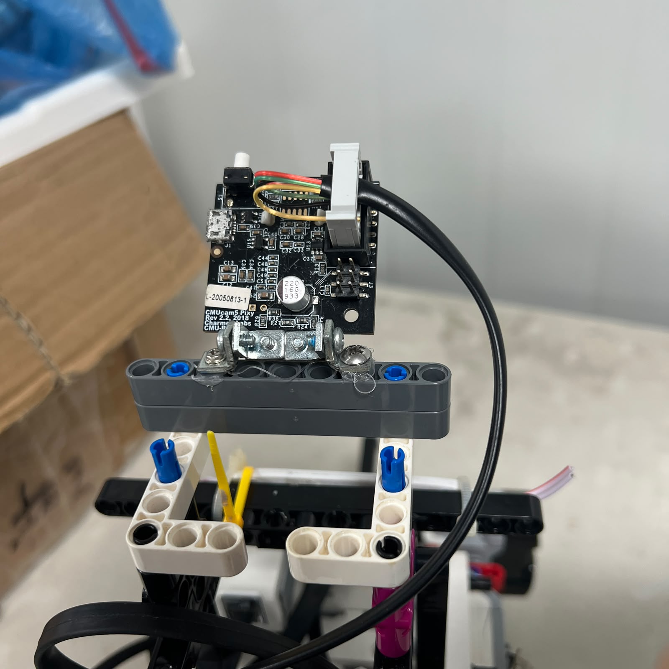
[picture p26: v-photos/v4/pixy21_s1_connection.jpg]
Pixy2.1 S1 connection
  
</p>

## Power Distribution

The battery supplies the EV3 Brick, and the EV3 provides the ports used by the
current motors and sensors.

The power architecture is intentionally simpler than several early experimental
configurations. Reducing extra converters, controllers, and communication
layers makes the system easier to reproduce and easier to diagnose.

| Device | Current Connection |
| --- | --- |
| EV3 Brick | EV3 Rechargeable Battery 45501 |
| EV3 Large Motor | Port A |
| EV3 Medium Motor | Port B |
| Open Gyro | S1 |
| Obstacle Pixy2.1 | S1 |
| Left Ultrasonic | S2 |
| Right Ultrasonic | S3 |
| Color Sensor | S4 |

<p align="center">
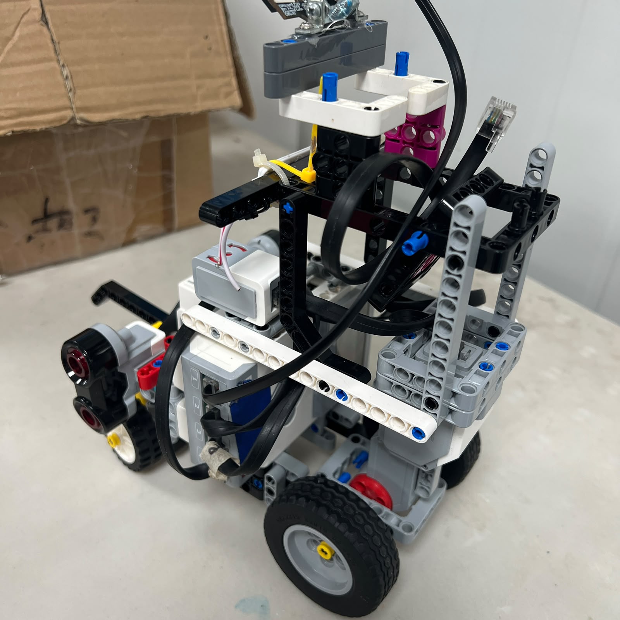
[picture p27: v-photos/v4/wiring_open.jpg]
Open wiring
  
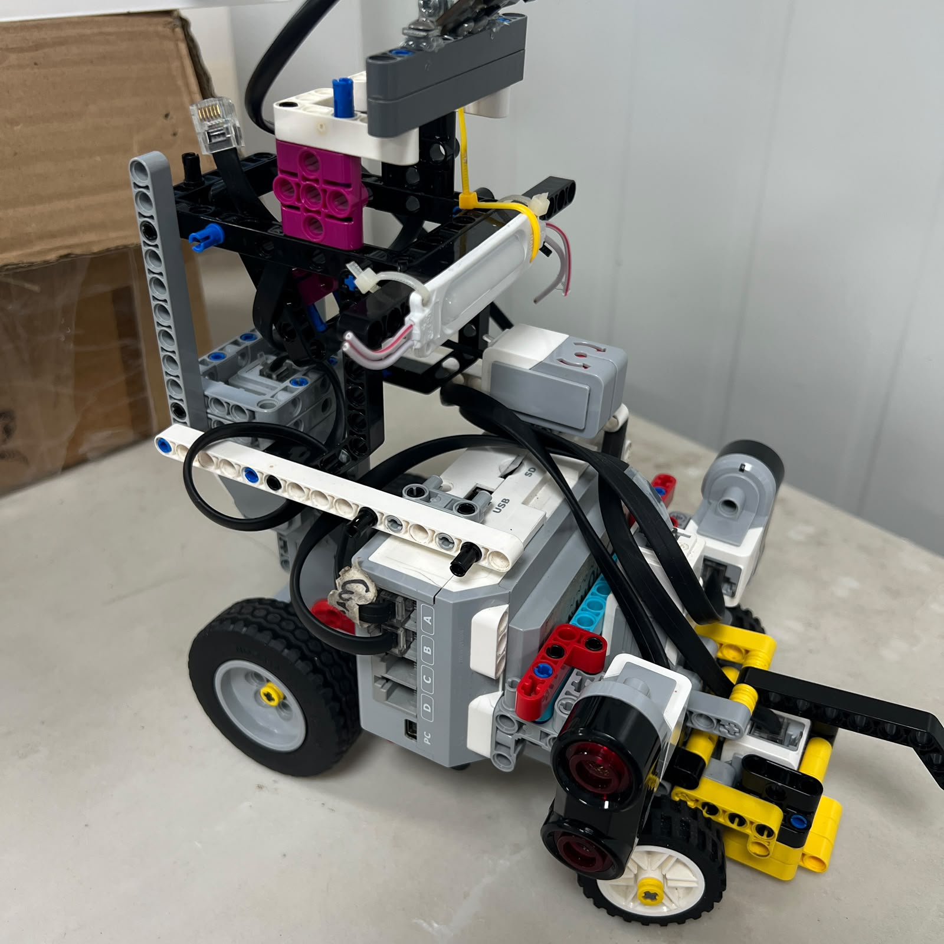
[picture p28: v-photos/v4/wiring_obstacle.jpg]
Obstacle wiring
  
</p>

## Sensor Failure Considerations

A sensor can fail in more than one way. It can stop reporting entirely, return
a temporary noisy value, observe the wrong physical surface, produce an
ambiguous classification, or remain physically misaligned while still returning
valid-looking data.

For this reason, Piolín's software increasingly uses validation and context
rather than trusting every measurement immediately.

The Color Sensor uses confirmation and event logic. Pixy detections are
validated before being selected. Ultrasonic readings can be filtered or ignored
when they are outside useful conditions. The gyro is interpreted together with
course state rather than as an isolated source of truth.

<p align="center">
  <a href="./docs/power_sensors/01_PowerSensorconfig.md">
    
  </a>
  <a href="./schemes/README.md">
    
  </a>
  <a href="./docs/reproducibility/03_wiring.md">
    
  </a>
</p>

---

# Software & Obstacle Strategy

## Software Overview

<p align="center">
  
</p>

Piolín's software architecture evolved from direct sensor reactions toward a
layered control system.

The earliest programs were useful because they made cause and effect simple to
observe. A color could trigger a steering command, or a wall distance could
generate a correction.

As more behaviors were added, direct reactions became harder to manage. A
sensor could be correct locally while the resulting steering command was wrong
for the larger maneuver.

The current architecture therefore separates raw sensing, validation,
perception, navigation state, active controller selection, control arbitration,
and final actuation.

```mermaid
flowchart LR
    S[Sensors] --> V[Validation]
    V --> P[Perception]
    P --> ST[Navigation State]
    ST --> C[Active Controller]
    C --> A[Control Arbitration]
    A --> M[Motor A + Motor B]
    M --> S
```

This structure also improves debugging. When a run fails, the team can ask
whether the problem began in the sensor data, in the interpretation of that
data, in state selection, in the selected controller, or in the mechanical
response of the robot.

## State-Based Thinking

State-based control is important because identical sensor values can mean
different things at different moments.

A short distance reading while driving normally may indicate a wall approach. A
similar reading while completing an obstacle maneuver may come from the pillar
or from a temporary vehicle angle.

Likewise, losing visual contact with a pillar can mean the target has been
passed, the camera has rotated away from it, the lighting changed, or the
object moved outside the field of view.

The state provides the context needed to interpret those events more safely.

## Open Challenge Strategy

The Open configuration combines the two lateral Ultrasonic Sensors, the Gyro
Sensor, and the Color Sensor.

S2 and S3 provide lateral geometry. The gyro provides heading and rotational
information. S4 provides physical floor landmarks.

The first confirmed floor event determines direction. Blue first corresponds to
counterclockwise navigation, while Orange first corresponds to clockwise
navigation.

Once direction is known, the software can interpret which physical side is
inner and which side is outer while still preserving the fixed S2-left and
S3-right naming.

<p align="center">
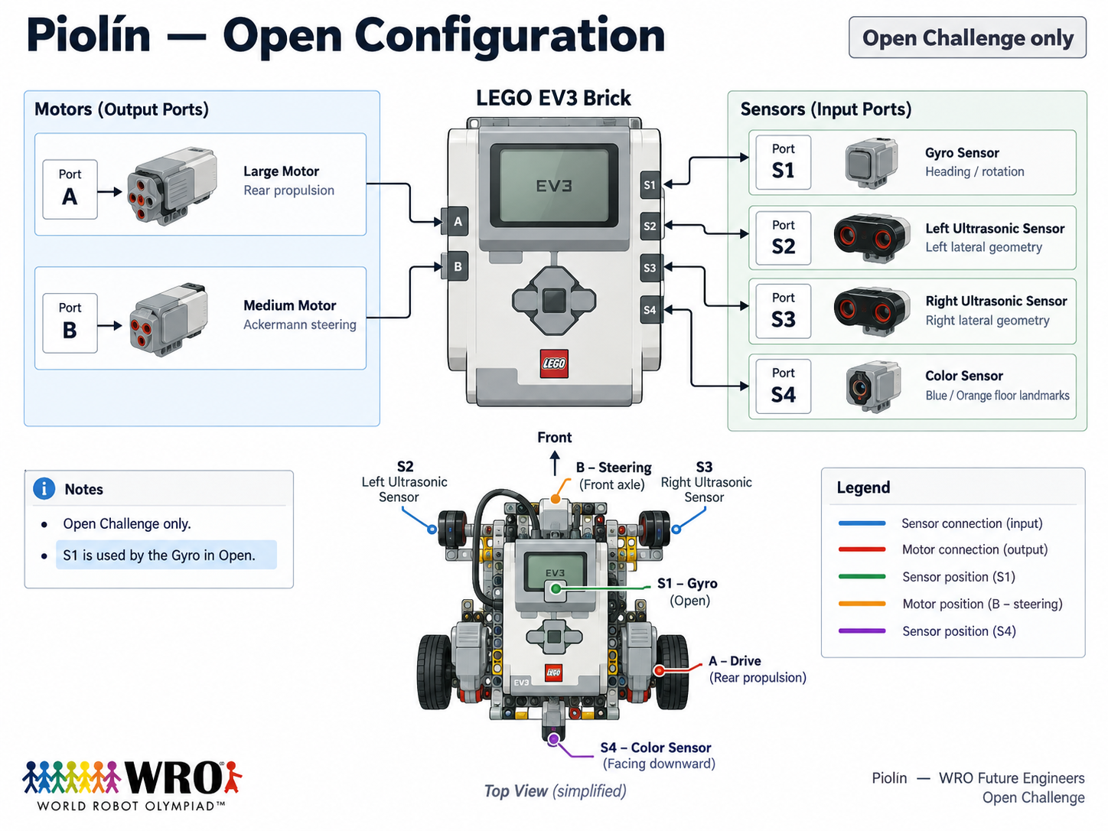
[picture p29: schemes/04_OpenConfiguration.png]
Open Challenge configuration
  
</p>

## Straight Navigation

Straight navigation is not treated as a demand to keep the steering motor
mathematically at zero.

The robot may require small corrections because the starting angle is
imperfect, the wheels are not perfectly aligned, the surface is not identical
everywhere, or the chassis drifts slightly.

Lateral ultrasonic geometry provides position information while the gyro helps
stabilize orientation.

The balance between these sources is important. A heading controller should not
ignore useful wall geometry, and a wall controller should not interpret every
geometry change as an ordinary lateral error.

## Gyro Heading Stabilization

A simplified gyro correction can be represented as:

$$
u_{gyro}=K_p e_\theta+K_d\frac{\Delta e_\theta}{\Delta t}
$$

The proportional component responds to the current heading error. The
derivative component responds to the rate of change of that error and helps
reduce aggressive oscillation.

The current Open development uses a PD-style gyro correction rather than
claiming a full PID controller with an integral term that is not part of the
documented current logic.

Controller gains are tuned through track testing because the same mathematical
gain can behave differently after mechanical changes.

## Corner Handling

Corners are one of the most important differences between simple wall following
and complete course navigation.

As Piolín begins to turn, the Ultrasonic Sensors stop observing the same
geometry that they saw during the straight section.

If the normal lateral controller remains dominant throughout the entire corner,
it can incorrectly fight the intended steering maneuver.

Corner handling therefore uses course-event information, geometry change, and
gyro rotation as different pieces of evidence.

The exact transition conditions are calibrated on the physical robot because
the final corner shape depends on steering geometry, speed, and sensor
placement.

## Color Events

A physical Blue or Orange marking can remain under S4 for multiple program
cycles.

If every raw sensor reading were counted independently, Piolín could
incorrectly count one physical line several times.

The event architecture separates classification from acceptance. A candidate
must be confirmed, accepted once, latched while the sensor remains over the
line, and released only after neutral floor has been observed.

```mermaid
flowchart LR
    C[Classify] --> F[Confirm]
    F --> A[Accept]
    A --> L[Latch]
    L --> N[Neutral Floor]
    N --> R[Re-arm]
```

This allows course progress to be represented by physical events instead of raw
samples.

## Obstacle Challenge Strategy

The Obstacle Challenge replaces the gyro with Pixy2.1.

The camera sees colored blocks, while the EV3 determines which detection is
relevant and what maneuver should follow.

The current signature convention is:

| Signature | Target | Rule |
| :---: | --- | --- |
| **sig1** | Pink | Parking reference |
| **sig2** | Red pillar | Pass on the **RIGHT** |
| **sig3** | Green pillar | Pass on the **LEFT** |

The key design rule is that the signature determines the passing side.

A Red pillar remains a right-side pass even if the pillar appears on the left
side of the camera image. A Green pillar remains a left-side pass even if its
image position changes.

This avoids confusing the rule-defined side with the camera's point of view.

<p align="center">
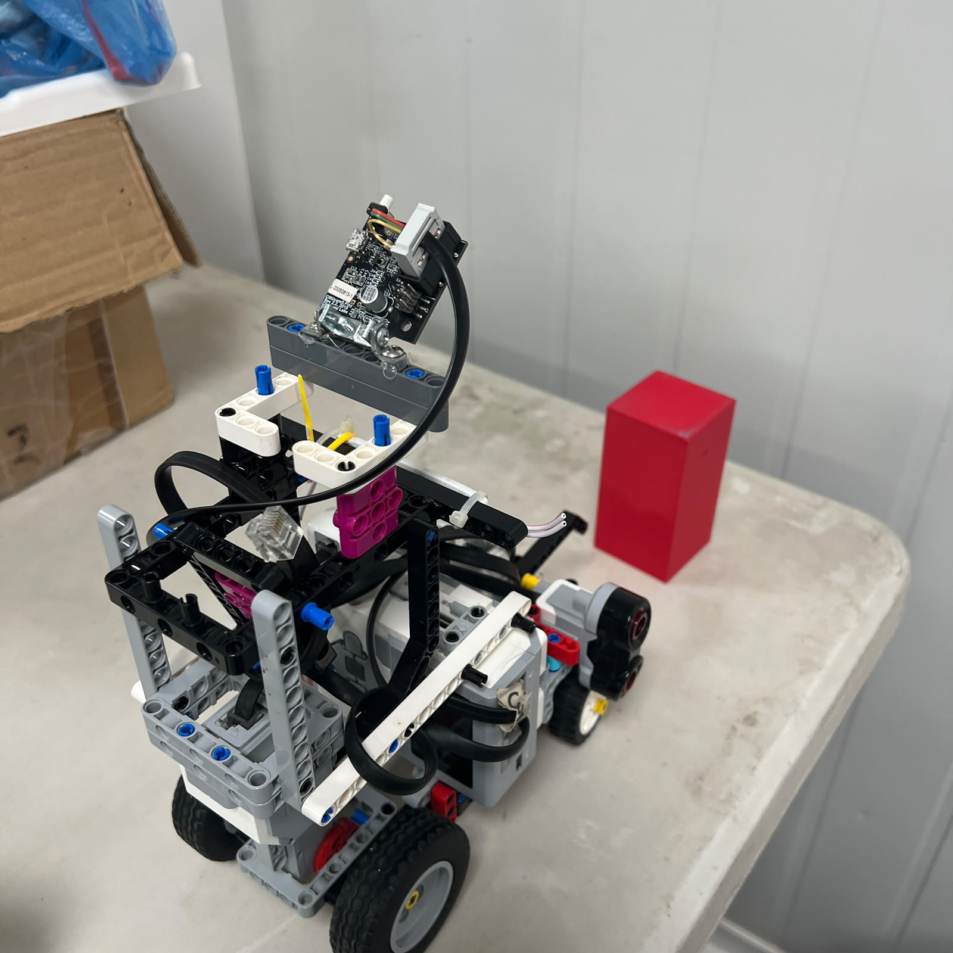
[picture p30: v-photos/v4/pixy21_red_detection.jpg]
Pixy Red detection
  
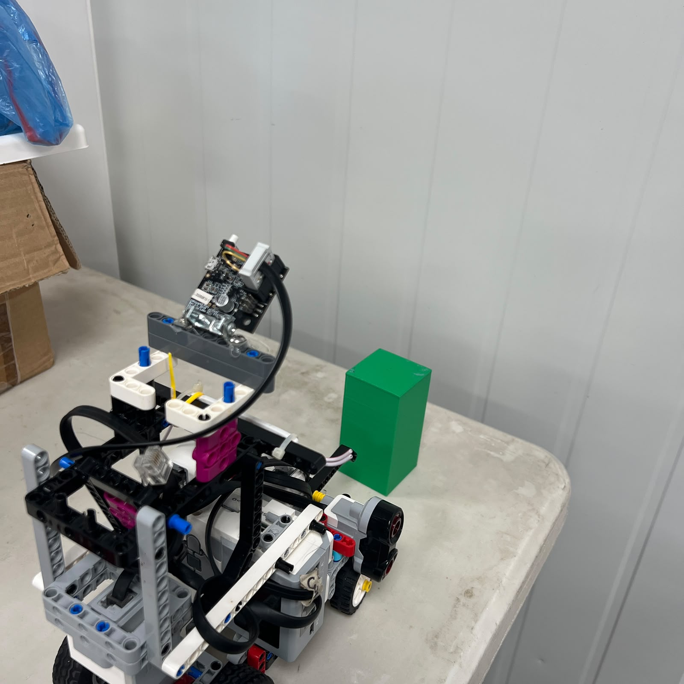
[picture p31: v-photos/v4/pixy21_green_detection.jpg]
Pixy Green detection
  
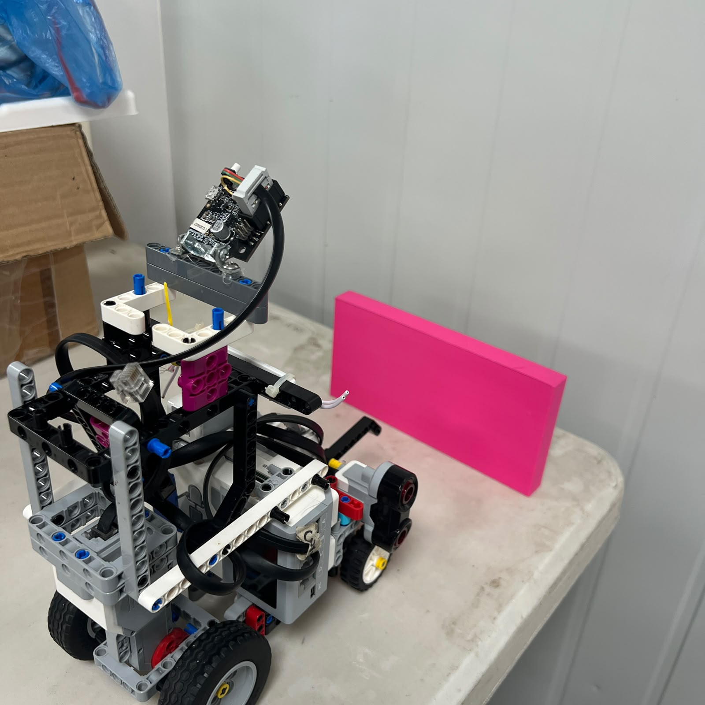
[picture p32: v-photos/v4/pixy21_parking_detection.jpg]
Pixy Pink parking detection
  
</p>

## Vision Geometry

Pixy2.1 provides more than a color signature.

The horizontal position can describe where the block appears across the field
of view. The vertical position and apparent size can contribute to an estimate
of which object is more relevant to the immediate maneuver.

These values are image-space observations. They are not automatically equal to
physical centimeters.

Piolín therefore uses them as relative perception information rather than
claiming direct metric distance unless a specific calibration supports that
conversion.

## Target Validation

Not every detected block should immediately control steering.

A weak reflection, distant object, partial color region, or ambiguous block may
not be the correct target.

The target-selection process therefore considers signature validity, block
size, image position, apparent relevance, and temporary continuity with the
previously selected target.

This reduces the chance that an irrelevant block suddenly takes control of the
robot trajectory.

## Target Commitment

Once Piolín begins to avoid a valid pillar, the software should not reverse its
rule-defined side simply because the camera view changes during the maneuver.

The active target therefore has a lifecycle rather than being reselected from
scratch during every control cycle.

This helps preserve Red-right and Green-left behavior while the chassis rotates
and the target moves through the image.

## Temporary Camera Loss

A camera can temporarily lose the pillar during a correct avoidance maneuver.

The object may leave the field of view, become partially hidden by the robot
geometry, become difficult to classify for a few frames, or appear differently
because of lighting.

Immediately abandoning the maneuver in response to one missing frame would make
the robot unstable.

Target memory and state context therefore allow a short visual loss without
immediately reversing the intended trajectory.

## Pass Confirmation

A pillar disappearing from the camera image does not prove that the robot has
physically passed it.

Pass confirmation is a separate problem.

The lateral Ultrasonic Sensors can contribute physical evidence because the
corresponding side distance may first decrease as the robot approaches the
obstacle region and then increase after the pillar is cleared.

The exact logic remains an area of testing, but the architectural distinction
is important: visual loss and physical pass completion are not the same event.

## Recovery

After passing a pillar, Piolín may be displaced from its normal navigation
corridor or may still be angled toward a wall.

Returning instantly to a strong normal controller can create a sudden steering
reversal.

Recovery is therefore treated as a dedicated part of the obstacle maneuver.

Its purpose is to help Piolín return toward useful geometry while normal
lateral control gradually becomes dominant again.

## Control Arbitration

Multiple controllers can request different steering directions at the same
time.

Normal navigation may want to move left while a pillar maneuver requires right
steering. A wall safety condition may request a stronger intervention than
either one.

Piolín has only one steering actuator, so there must be one final steering
decision.

The control hierarchy can be summarized as critical safety first, active
maneuver second, and normal navigation third.

```mermaid
flowchart TD
    A[Critical Safety] --> D{Required?}
    D -- Yes --> S[Safety Command]
    D -- No --> M{Active Maneuver?}
    M -- Yes --> C[Maneuver Command]
    M -- No --> N[Normal Navigation]
    S --> B[Motor B]
    C --> B
    N --> B
```

This prevents independent controllers from fighting for Motor B.

## Parking Strategy

Parking is treated as a dedicated navigation sequence rather than a
fixed-duration final command.

The intended sequence begins only after course progress indicates that parking
is allowed.

During Obstacles, the Pink Pixy signature can help identify the parking
reference. Encoder movement, steering state, and lateral ultrasonic geometry
can provide additional physical information.

```mermaid
flowchart LR
    C[Course Complete] --> E[Eligible]
    E --> P[Parking Reference]
    P --> A[Approach]
    A --> EN[Entry]
    EN --> AL[Align]
    AL --> F[Final Position]
    F --> S[STOP]
```

The exact entry and stopping parameters remain subject to physical calibration.

<p align="center">
  <a href="./docs/software_obstacles_strategy/01_SWArchitecture.md">
    
  </a>
  <a href="./docs/software_obstacles_strategy/06_obstaclestrateg.md">
    
  </a>
  <a href="./embed/04_ControlArbitration.md">
    
  </a>
</p>

---

# Systems Thinking & Engineering Decisions

## Engineering Approach

<p align="center">
  
</p>

Piolín did not reach its current architecture through one successful prototype.

The project includes hardware failures, non-compliant experimental designs,
slow but mechanically useful configurations, sensor experiments, multiple
steering revisions, camera changes, and control strategies that were later
replaced.

These unsuccessful stages are preserved because they explain why the current
robot exists in its present form.

## Engineering Method

When a run fails, we try to identify the first incorrect behavior rather than
focusing only on the final visible collision.

The final crash may be several seconds after the real failure began.

The first problem may have been a sensor interpretation, a steering command, a
target-selection error, a state transition, a mechanical alignment issue, or an
interaction between two controllers.

Our engineering process therefore follows a repeatable cycle.

```mermaid
flowchart LR
    O[Observe] --> F[Find First Failure]
    F --> H[Hypothesis]
    H --> C[One Change]
    C --> T[Test]
    T --> D{Improved?}
    D -- Yes --> K[Keep]
    D -- No --> R[Revert]
    K --> DOC[Document]
    R --> H
```

Changing one meaningful variable at a time makes it easier to understand which
modification actually affected the behavior.

## Why We Preserve Failures

A failed design can still be valuable if it answers an engineering question.

The Yahboom failure changed the way the team thought about hardware reliability
and complexity.

A mechanically functional but non-compliant prototype reinforced the importance
of treating WRO rules as design constraints from the beginning.

A stronger but slow configuration showed that mechanical stability and
competitive movement cannot be separated.

Competition experience demonstrated that one successful run is not the same as
repeatability.

These lessons are documented so the repository shows the reasoning process
rather than only the final hardware.

## Design Constraints

The vehicle must satisfy the mechanical and operational constraints of the
Future Engineers challenge.

At the same time, Piolín has practical internal constraints created by the EV3
port count, the geometry of the chassis, the available steering range, sensor
field of view, cable routing, and the need to switch S1 between gyro and
Pixy2.1.

Good engineering decisions must respect both rule constraints and physical
constraints.

## Trade-Offs

Many decisions involve a trade-off instead of one universally correct answer.

A stronger steering correction can reduce one type of drift but may create
oscillation.

A slower speed can increase reaction time but may make the complete run
inefficient.

A camera position can increase visibility in one region while reducing it
elsewhere.

More sensors can provide more information but also create more wiring,
interpretation, and controller-conflict problems.

The trade-off documentation records why particular compromises were selected.

## Risk Management

The team also considers what happens when assumptions fail.

The Color Sensor may see an ambiguous floor value. Pixy2.1 may lose a target
temporarily. An Ultrasonic Sensor may see an unusual wall angle. Steering may
reach a mechanical limit. A software state may remain active longer than
expected.

Risk mitigation therefore includes validation, bounded steering, target memory,
event latching, safe-stop behavior, calibration checks, and testing under
multiple starting conditions.

## Regression Testing

A change is not automatically an improvement because one test becomes better.

The change also has to be tested against previously successful situations.

This is particularly important in autonomous navigation because one new
correction can solve a corner while damaging straight driving, or improve one
obstacle while causing another pillar to be approached incorrectly.

Regression testing protects previous successful behavior from being lost during
rapid tuning.

<p align="center">
  <a href="./docs/systems_engineering/01_engineeringprocess.md">
    
  </a>
  <a href="./docs/systems_engineering/02_decisionlog.md">
    
  </a>
  <a href="./docs/systems_engineering/04_tradeoffs.md">
    
  </a>
  <a href="./docs/systems_engineering/06_whatdidntwork.md">
    
  </a>
</p>

---

# Engineering Achievements

## Key Engineering Outcomes

The strongest improvements in Piolín are documented architectural changes
rather than unsupported claims about perfect accuracy, zero latency, or maximum
speed.

The current robot has a clear separation between propulsion and steering, fixed
physical identities for the lateral sensors, a round-specific S1 architecture,
event-based floor detection, structured obstacle target handling, control
arbitration, and dedicated recovery and parking concepts.

| Engineering Development | Why It Matters |
| --- | --- |
| **Ackermann steering refinement** | Provides car-like steering with one dedicated steering actuator |
| **Separated propulsion and steering** | Motor A drives while Motor B steers |
| **Round-specific S1** | Uses the information source needed by each challenge |
| **Fixed S2/S3 convention** | Keeps left and right sensor identities unambiguous |
| **Color event lifecycle** | Prevents one physical marking from being counted repeatedly |
| **Pixy target validation** | Reduces reactions to weak or irrelevant visual detections |
| **Target memory** | Allows short camera losses without immediately abandoning a maneuver |
| **Pass confirmation concept** | Separates visual disappearance from real obstacle clearance |
| **Recovery behavior** | Helps return the vehicle toward useful geometry |
| **Control arbitration** | Prevents competing controllers from fighting for Motor B |
| **3D-printed sensor integration** | Improves repeatability of physical sensor installation |
| **Testing methodology** | Makes changes easier to compare, keep, or revert |

---

# Evolution of Piolín

## Evolution Overview

PiolínTech began developing the project in June 2025.

The current robot is the result of many mechanical and sensing configurations
rather than one uninterrupted build.

Early stages focused on understanding basic motion and vehicle construction.
Later stages increasingly focused on steering geometry, sensor placement, track
navigation, perception, repeatability, and software architecture.

The evolution documents are intended to show how engineering decisions
accumulated over time.

## Phase 1 — Initial EV3 Prototype

Phase 1 represents early EV3-based experimentation with basic vehicle movement,
sensor placement, and structural concepts.

The goal was not to present a competition-ready system. It was to understand
what the vehicle needed mechanically before more advanced control could be
trusted.

The first phase created the baseline from which later mechanical and sensing
questions could be asked.

## Phase 2 — Mechanical and Navigation Development

Phase 2 focused more strongly on vehicle geometry, steering development,
lateral sensing, and the organization of the chassis.

This phase helped connect mechanical layout with navigation behavior.

It also reinforced the idea that sensor placement is not independent from
control logic.

## Phase 3 — Sensor, Vision, and Control Experimentation

Phase 3 included extensive experimentation with sensing and vision.

HuskyLens and Arduino Nano were investigated as one possible obstacle
architecture. Pixy2.1 was later evaluated as a more direct vision option.

The phase also exposed controller-conflict problems and the need to separate
perception, active maneuvers, and normal navigation.

## Phase 4 — Current Competition Architecture

Phase 4 represents the current competition architecture.

The EV3 remains the central controller. Motor A provides rear propulsion. Motor
B provides Ackermann steering. S2 remains left ultrasonic, S3 remains right
ultrasonic, and S4 remains the downward Color Sensor.

S1 is round-specific: Gyro for Open and Pixy2.1 for Obstacles.

Phase 4 is current, but individual navigation parameters and maneuvers continue
to be tuned through physical testing.

<p align="center">
  <a href="./models/evolution/Phase1.md">
    
  </a>
  <a href="./models/evolution/Phase2.md">
    
  </a>
  <a href="./models/evolution/Phase3.md">
    
  </a>
  <a href="./models/evolution/phase4.md">
    
  </a>
</p>

---

# V4 — Current Competition Architecture

## Current Physical Reference

<p align="center">
  
</p>

V4 consolidates the present drivetrain, Ackermann steering, EV3 controller, two
lateral Ultrasonic Sensors, downward Color Sensor, and round-specific S1
configuration.

The images below provide the principal six-view physical record of the current
vehicle.

| Front | Rear | Left |
| :---: | :---: | :---: |
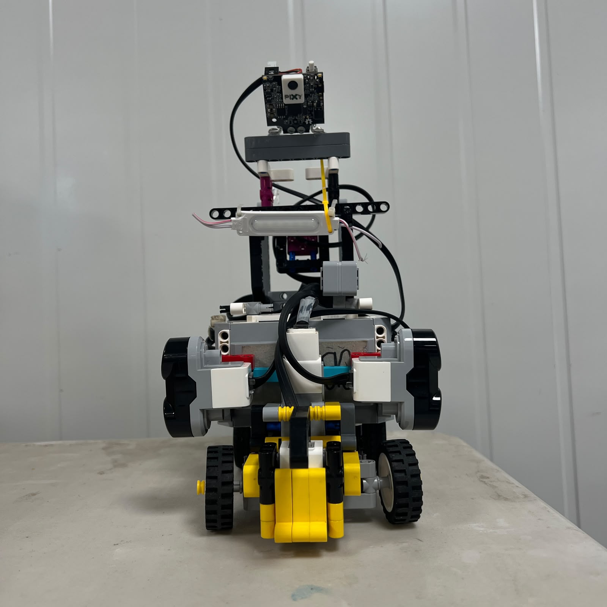
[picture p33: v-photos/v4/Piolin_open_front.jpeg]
Piolín front
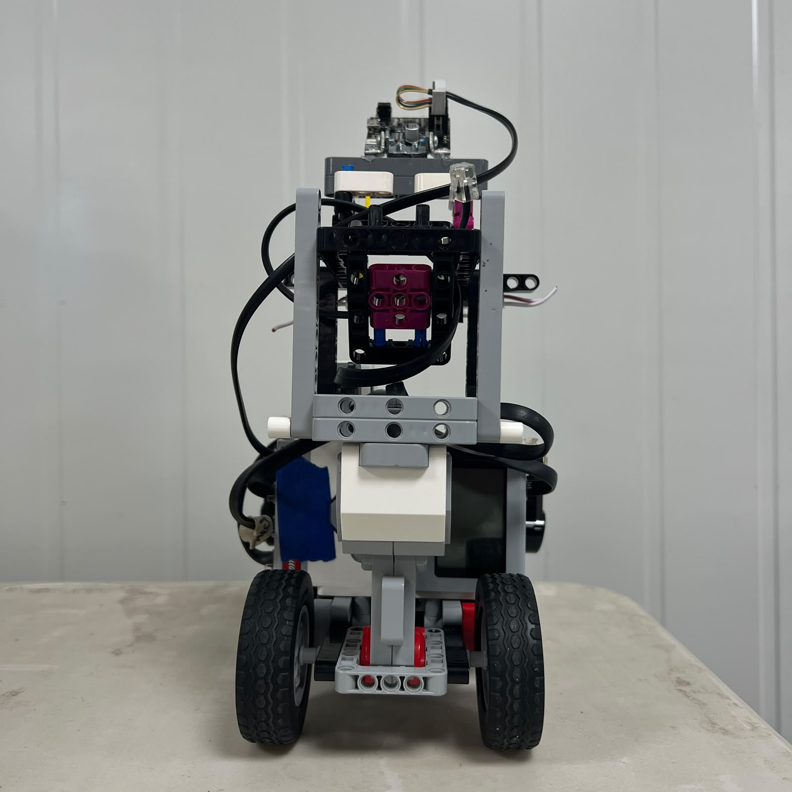
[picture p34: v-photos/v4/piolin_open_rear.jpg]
Piolín rear
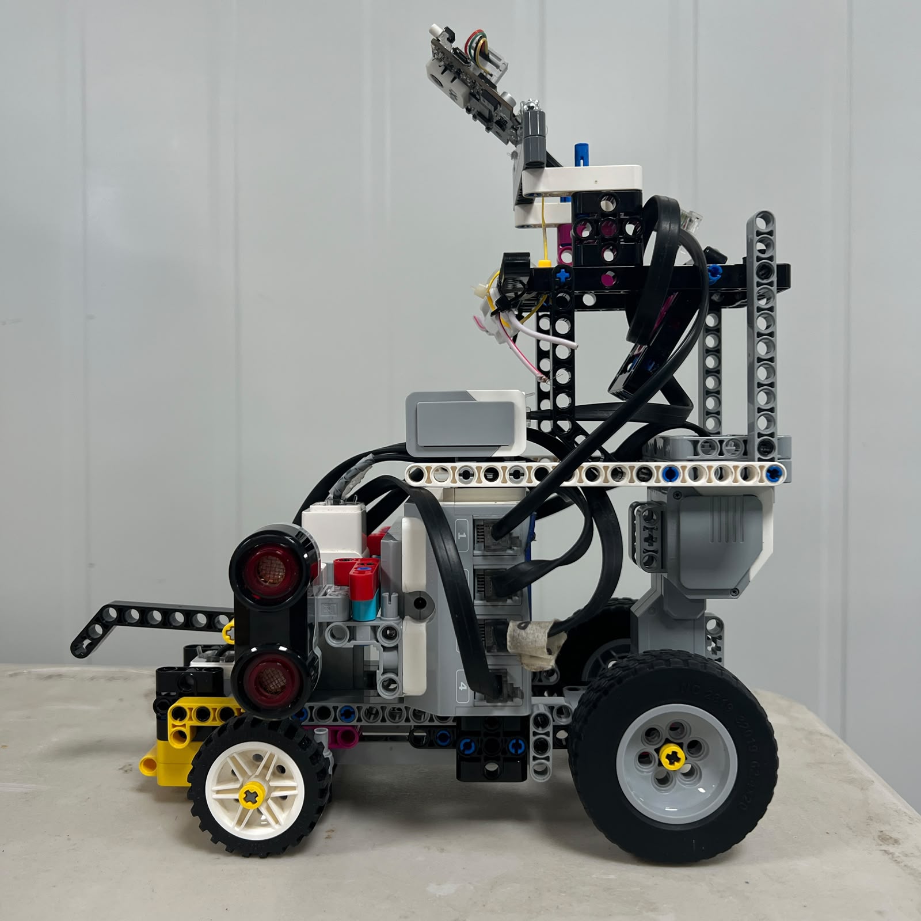
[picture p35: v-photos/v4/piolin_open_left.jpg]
Piolín left
|  |  |  |
| **Right** | **Top** | **Bottom** |
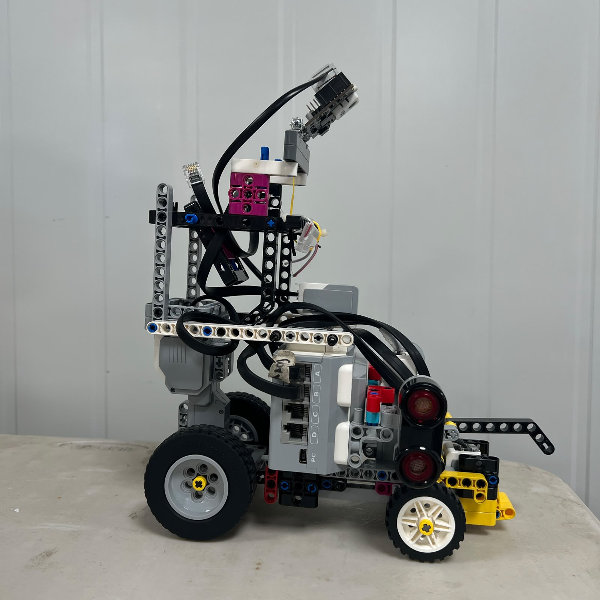
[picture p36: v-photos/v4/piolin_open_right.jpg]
Piolín right
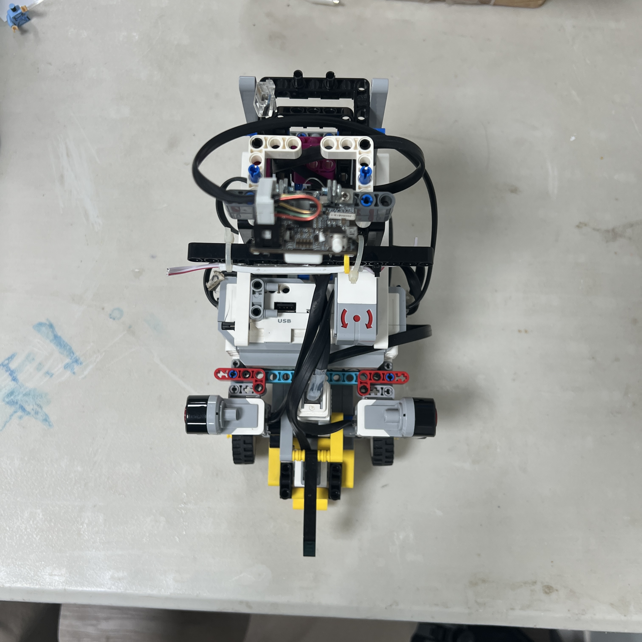
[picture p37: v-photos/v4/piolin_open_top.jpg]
Piolín top
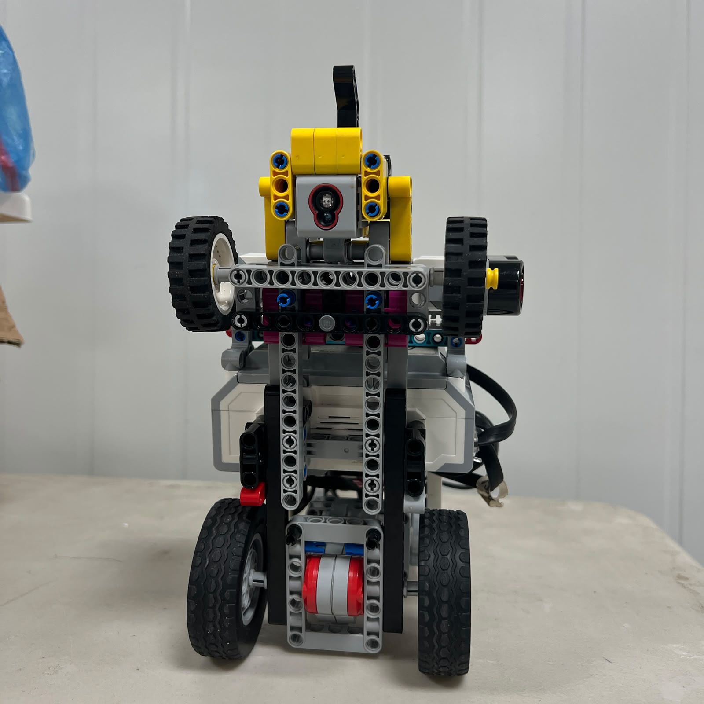
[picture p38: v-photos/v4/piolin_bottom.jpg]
Piolín bottom
|  |  |  |

These photographs are complemented by close-up evidence of the chassis,
steering system, drivetrain, motors, sensors, battery, EV3 ports, Pixy
detections, wiring, and track tests.

<p align="center">
  <a href="./v-photos/README.md">
    
  </a>
  <a href="./t-gtku/timeline.md">
    
  </a>
</p>

---

# 3D-Printed Components

## Manufacturing and Sensor Integration

Piolín uses custom 3D-printed parts where a repeatable sensor installation
provides a practical advantage.

The Color Sensor casing helps maintain a more controlled optical environment
around S4 and helps preserve a repeatable physical relationship between the
sensor and the floor.

The two-part Pixy2.1 casing provides mechanical support and protection while
helping maintain a consistent camera position.

These parts are treated as part of the calibrated sensing system rather than
decorative accessories.

A different camera angle changes the x and y positions of detected blocks. A
different Color Sensor height can change reflection and RGB values.

Mechanical sensor installation and software calibration therefore have to be
considered together.

The current printed parts were manufactured using an Anet ET4X printer and
OVERTURE High Speed PLA 1.75 mm filament.

The documented print setup uses a nozzle temperature of 200 °C, a bed
temperature of 80 °C, and the printer's 100% speed setting.

The repository does not claim unrecorded layer height, infill, supports, or
print times when those values were not documented.

<p align="center">
  Anet ET4X
  OVERTURE PLA
</p>

### Printable Files

- [ColorSensorCasing.stl](./models/3dprint/ColorSensorCasing.stl)
- [PIXY_Case1.stl](./models/3dprint/PIXY_Case1.stl)
- [PIXY_Case2.stl](./models/3dprint/PIXY_Case2.stl)

<p align="center">
  <a href="./models/3dprint/01_PrintingProcess.md">
    
  </a>
  <a href="./models/3dprint/02_ColorSensorCasing_Print.md">
    
  </a>
  <a href="./models/3dprint/03_PixyCase_Print.md">
    
  </a>
</p>

---

# Reproducibility & GitHub Quality

## Reproducibility Overview

<p align="center">
  
</p>

The repository is designed so another reader can understand how Piolín is
assembled, connected, programmed, calibrated, tested, and diagnosed.

Reproducibility requires more than a list of parts.

Sensor orientation, motor port assignment, steering center, software
dependencies, physical configuration, and calibration can all change the
resulting robot behavior.

For this reason, the repository contains a Bill of Materials, wiring
documentation, electrical schemes, software setup instructions, calibration
procedures, testing protocols, troubleshooting information, source code, STL
files, photographs, and videos.

## Software Preparation and Upload

Before either competition program is executed, the physical robot is checked
first.

Motor A and Motor B must be connected correctly. The steering mechanism must be
physically centered. S2 and S3 must correspond to the left and right Ultrasonic
Sensors. S4 must be installed correctly above the floor.

The correct round-specific sensor is then installed on S1.

Open requires the EV3 Gyro Sensor. Obstacles requires Pixy2.1.

The corresponding Python program is transferred to the EV3 and the necessary
sensors are calibrated before a full course attempt.

A controlled test is performed first so debug output and physical behavior can
be inspected without immediately risking a full-speed collision.

The complete setup process is documented in the software-setup guide.

## Calibration

Calibration is treated as a system process rather than only a
software-threshold adjustment.

Steering centering, Ultrasonic Sensor orientation, Color Sensor height, gyro
reset conditions, Pixy2.1 position, and camera signature training can all
influence the autonomous result.

If a mechanical sensor installation changes, the team does not assume that old
software values remain valid.

The corresponding subsystem is tested again before its previous calibration is
trusted.

## Testing

A single successful run is not sufficient evidence that a change is reliable.

Tests are repeated from different valid starting positions and under comparable
conditions.

The team observes start acquisition, straight driving, corner entry, corner
exit, lateral geometry, color events, target selection, obstacle side, pass
completion, recovery, parking, and stopping behavior.

A modification is evaluated both against the original problem and against
previously successful situations.

## Troubleshooting

Troubleshooting begins with the physical system.

If Piolín behaves incorrectly, the team checks sensor connections, steering
center, mechanical interference, wheel alignment, battery state, sensor
position, and visible damage before assuming that the software is responsible.

The software is then inspected through debug information, state behavior,
sensor values, and the first unexpected transition.

This order helps prevent software from compensating for a physical fault that
should be repaired directly.

<p align="center">
  <a href="./docs/reproducibility/02_BOM.pdf">
    
  </a>
  <a href="./docs/reproducibility/03_wiring.md">
    
  </a>
  <a href="./docs/reproducibility/05_softwaresetup.md">
    
  </a>
  <a href="./docs/reproducibility/06_HowToCalibrate.md">
    
  </a>
</p>

---

# Source Code

## Published Competition Programs

<p align="center">
  
</p>

The published code is separated by competition round.

Each round includes a Python program and a dedicated explanation so a reader
can understand the purpose of the program, the hardware assumptions, the main
variables, the control flow, and the limitations of that version.

| Challenge | Source Code | Explanation |
| --- | --- | --- |
| **Round 1 — Open** | [ev3v1.py](./code/round1/ev3v1.py) | [r1_exp.md](./code/round1/r1_exp.md) |
| **Round 2 — Obstacles** | [ev3v1.py](./code/round2/ev3v1.py) | [r2_exp.md](./code/round2/r2_exp.md) |

The source-code folders are intended to show the software evolution clearly
rather than hiding older development concepts after more advanced versions were
created.

---

---

# Technical Schemes and Flowcharts

## Diagram Organization

Hardware and software diagrams are stored separately so a reader can
distinguish the physical architecture from the control logic immediately. The
`schemes/` directory contains electrical, port, and configuration diagrams,
while `embed/` contains software, perception, parking, and engineering-process
flowcharts.

This separation keeps the repository readable and prevents a hardware wiring
diagram from being confused with a software-state diagram. Both groups are
linked directly from the README so judges can move from the overview to the
detailed evidence without manually searching the folder tree.

<p align="center">
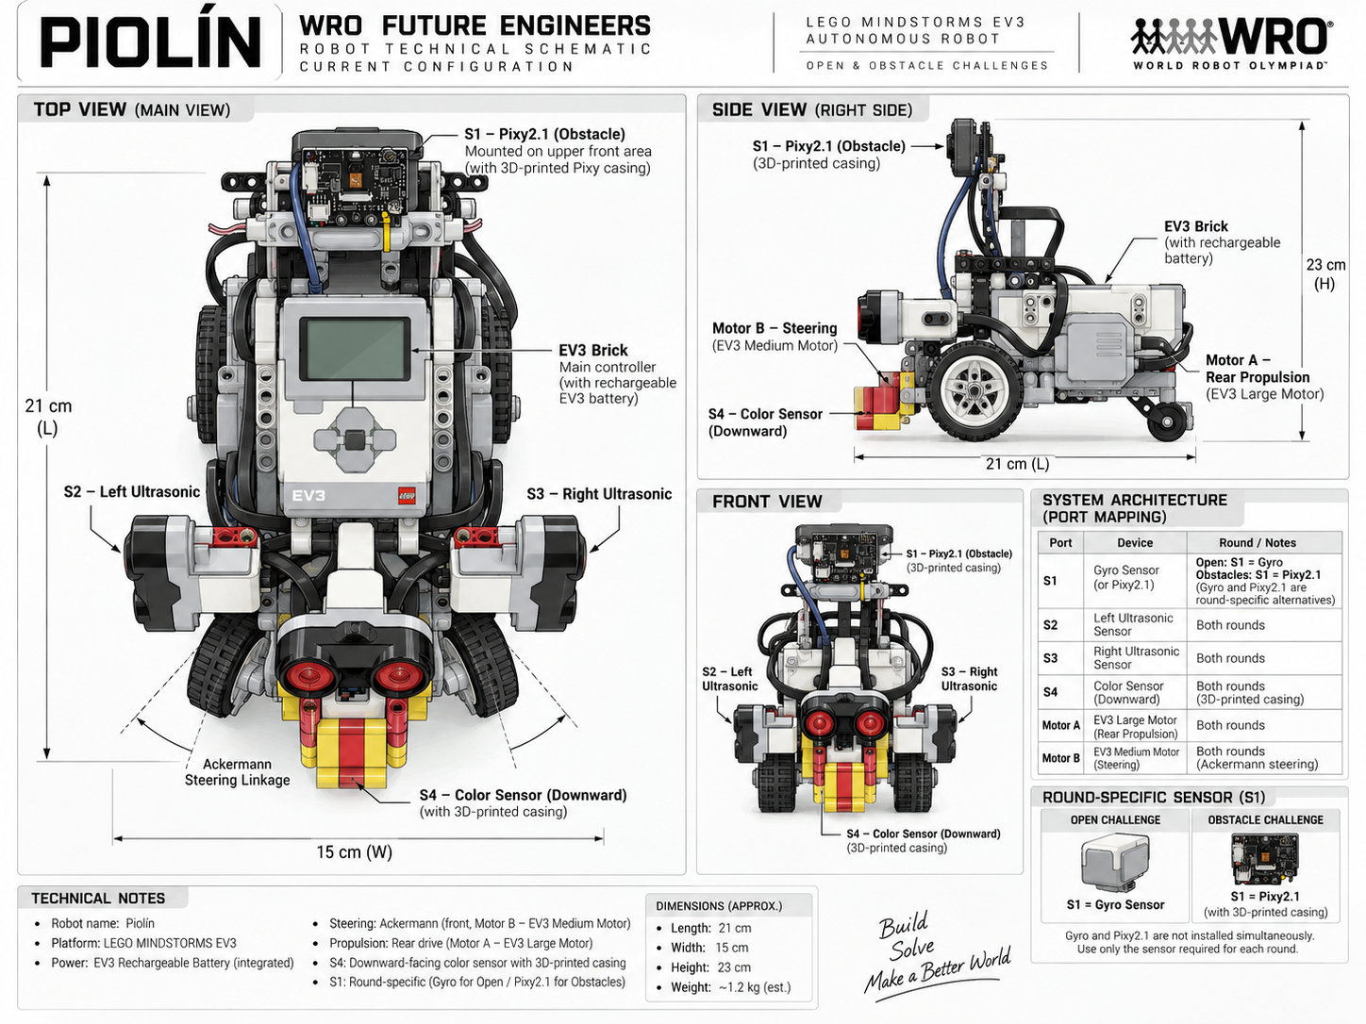
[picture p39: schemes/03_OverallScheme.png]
Piolín overall technical scheme
  
</p>

## Hardware Schemes

- [**01 — EV3 KiCad Reference**](./schemes/01_EV3Kicad.png) — Technical EV3 electrical reference used alongside the robot documentation.
- [**02 — EV3 Port Map**](./schemes/02_EV3PortMap.png) — Current motor and sensor assignments for Piolín.
- [**03 — Overall Scheme**](./schemes/03_OverallScheme.png) — High-level electromechanical representation of the robot.
- [**04 — Open Configuration**](./schemes/04_OpenConfiguration.png) — Current Open Challenge sensor and motor configuration.
- [**Schemes README**](./schemes/README.md) — Explanation of the purpose and scope of each hardware scheme.

## Software and Engineering Flowcharts

- [**01 — Navigation State Flow**](./embed/01_NVStateFC.md) — State-based navigation logic.
- [**02 — Vision Processing**](./embed/02_VProcessing.md) — Processing path from Pixy detections to useful perception information.
- [**03 — Torque Calculation**](./embed/03_TorqueCalc.png) — Mechanical torque reference.
- [**04 — Control Arbitration**](./embed/04_ControlArbitration.md) — Priority between safety, active maneuvers, and normal navigation.
- [**05 — Obstacle Strategy**](./embed/05_ObstacleStrategyFC.md) — Full pillar-detection and avoidance flow.
- [**06 — Color Event Logic**](./embed/06_ColorEventFC.md) — Confirmation, latching, release, and rearming of physical floor events.
- [**07 — Parking State Flow**](./embed/07_ParkingStateFC.md) — Parking-state progression.
- [**08 — Parking Calibration**](./embed/08_ParkingCalibrationFC.md) — Structured parking-calibration process.
- [**09 — Engineering Process**](./embed/09_EngineeringProcessFC.md) — Observe, hypothesize, test, compare, and document cycle.
- [**10 — System Architecture**](./embed/10_SystemArchitectureFC.md) — High-level relationship between sensing, control, and actuation.
- [**Flowchart Index**](./embed/README.md) — Complete index of software and engineering diagrams.

<p align="center">
  <a href="./schemes/README.md">
    
  </a>
  <a href="./embed/README.md">
    
  </a>
</p>

---

# Legacy Development

## Historical Scope

Not every experiment became part of the current robot. Earlier development
included different sensor arrangements and a HuskyLens plus Arduino Nano vision
bridge. These configurations provided useful information about communication
complexity, target detection, sensor reliability, and the difficulty of
coordinating multiple control layers.

The current competition robot does not use HuskyLens or Arduino Nano. Legacy
material is intentionally separated from current documentation so historical
experiments can still demonstrate the engineering process without creating
ambiguity about the hardware that is installed today.

## Legacy Files

- [**Legacy Notice**](./docs/legacy/00_LEGACY_NOTICE.md) — Defines what is historical and what is current.
- [**HuskyLens Development**](./docs/legacy/01_HuskyLens.md) — Previous vision-system experimentation.
- [**Previous Testing & Analysis**](./docs/legacy/02_PTesting%26Analysis.md) — Historical test material and observations.
- [**Previous Testing Scheme**](./docs/legacy/PTScheme.png) — Visual evidence from earlier development.
- [**Previous Circuit Image**](./docs/legacy/PTechcircuit_image.png) — Previous electrical-development reference.

<p align="center">
  <a href="./docs/legacy/00_LEGACY_NOTICE.md">
    
  </a>
</p>

---

# Project History

## Development Timeline

PiolínTech began this project in June 2025. Since then, the vehicle has passed
through early prototypes, a major hardware failure, mechanically useful but
non-compliant experiments, stronger but slower designs, WRO competition
experience, steering development, several sensing configurations, vision
experiments, and the current V4 architecture.

The timeline is preserved because the current robot is easier to understand
when the decisions that preceded it remain visible. Some prototypes taught us
about competition constraints, some exposed hardware reliability problems, and
others revealed how closely mechanical geometry and autonomous control are
connected.

## From Early Prototypes to V4

The current architecture did not replace every earlier idea. Instead, the team
kept the parts that remained useful, modified the parts that created
repeatability problems, and removed systems that added more complexity than
value.

That process produced the present EV3-centered architecture, the dedicated
Motor A / Motor B responsibilities, the fixed S2-left and S3-right convention,
the S4 floor-sensing role, and the round-specific S1 design.

<p align="center">
  <a href="./t-gtku/timeline.md">
    
  </a>
</p>

---

# Engineering Roadmap

## Current Development Priorities

The current roadmap focuses on reliability and calibration rather than adding
unnecessary new hardware. The main engineering question is no longer how many
features can be added to Piolín, but how consistently the existing architecture
can perform under different valid starting conditions and track situations.

## Open Challenge Priorities

Open development focuses on start acquisition, straight-line stability, corner
entry, rotation, corner exit, geometric reacquisition, course-event counting,
and final parking behavior. Improvements are tested against multiple starting
positions so one successful case does not hide a weakness somewhere else on the
course.

## Obstacle Challenge Priorities

Obstacle development focuses on stable Red and Green target selection,
preserving the correct WRO passing side, preventing temporary camera loss from
cancelling a valid maneuver, confirming that a pillar has physically been
cleared, and recovering toward useful lateral geometry afterward.

## Regression Testing Priority

Regression testing remains important in both rounds. A new adjustment is not
accepted simply because one failure disappears. Previously successful cases are
tested again so the team can identify whether the modification solved the
original problem without creating a new one elsewhere.

| Area | Current Focus |
| --- | --- |
| **Open Start** | Reliable acquisition from valid starting positions |
| **Open Straight Driving** | Stable lateral geometry with controlled steering response |
| **Open Corners** | Repeatable entry, rotation, exit, and reacquisition |
| **Course Events** | One accepted software event for each physical marking |
| **Obstacle Detection** | Select the most relevant valid Pixy target |
| **Passing Side** | Preserve Red-right and Green-left behavior |
| **Pass Confirmation** | Distinguish temporary visual loss from physical clearance |
| **Recovery** | Return toward useful track geometry after a pillar |
| **Parking** | Improve approach, entry, alignment, and stopping |
| **Regression Testing** | Protect previously successful behavior |

---

# Repository Structure

## Directory Map

The repository is organized by engineering purpose so current hardware,
software, evidence, manufacturing files, and historical development remain easy
to distinguish.

```text
WRO2026-FE-PiolinTech/
├── code/
│   ├── round1/
│   │   ├── ev3v1.py
│   │   └── r1_exp.md
│   └── round2/
│       ├── ev3v1.py
│       └── r2_exp.md
├── docs/
│   ├── components/
│   ├── legacy/
│   ├── mobility_mechanical/
│   ├── power_sensors/
│   ├── project_overview/
│   ├── reproducibility/
│   ├── software_obstacles_strategy/
│   │   └── parking/
│   └── systems_engineering/
├── embed/
├── models/
│   ├── 3dprint/
│   └── evolution/
├── schemes/
├── t-gtku/
├── v-photos/
│   ├── v1/
│   ├── v2/
│   ├── v3/
│   └── v4/
├── videos/
└── README.md
```

## Folder Roles

`code/` contains the published programs and their explanations. `docs/`
contains the detailed engineering documentation. `embed/` contains software and
engineering flowcharts. `models/` contains 3D-printing files and the documented
evolution of the robot. `schemes/` contains hardware-oriented technical
diagrams. `t-gtku/` contains team and timeline material. `v-photos/` provides
physical evidence across robot generations, and `videos/` contains autonomous
demonstrations.

---

# Detailed Repository Navigation

## Components

The component files document the individual hardware elements before they are
combined into the complete system.

- [**Hardware Overview**](./docs/components/01_Hardwareoverview.md) — Current hardware architecture at a glance.
- [**EV3 Controller**](./docs/components/02_EV3.md) — Main onboard controller and port structure.
- [**Motors**](./docs/components/03_Motors.md) — Drive and steering motors.
- [**Steering Motor**](./docs/components/04_SteeringMotor.md) — Motor B and the steering mechanism.
- [**Ultrasonic Sensors**](./docs/components/05_UltrasonicSensors.md) — Lateral S2 and S3 sensing.
- [**Color Sensor**](./docs/components/06_ColorSensor.md) — Downward S4 floor sensing.
- [**Pixy Vision**](./docs/components/07_PixyVision.md) — Pixy2.1 obstacle perception.
- [**Battery**](./docs/components/08_Battery.md) — EV3 Rechargeable Battery 45501.
- [**Power Distribution**](./docs/components/09_PowerDistribution.md) — Current power path through the EV3 architecture.
- [**Other Components**](./docs/components/10_OtherComponents.md) — Additional physical components used by Piolín.

## Source Code

The source-code directory is intentionally separated by round because Open and
Obstacles use different S1 devices and different perception requirements.

- [**Round 1 EV3 V1**](./code/round1/ev3v1.py) — Open Challenge source code.
- [**Round 1 Explanation**](./code/round1/r1_exp.md) — Technical explanation of the Round 1 version.
- [**Round 2 EV3 V1**](./code/round2/ev3v1.py) — Obstacle Challenge source code.
- [**Round 2 Explanation**](./code/round2/r2_exp.md) — Technical explanation of the Round 2 version.

## 3D Models and Manufacturing

The manufacturing files make the custom sensor components reproducible and
connect the STL geometry with installation and recalibration.

- [**Printing Process**](./models/3dprint/01_PrintingProcess.md) — Printer, filament, manufacturing workflow, inspection, and installation.
- [**Color Sensor Casing Print**](./models/3dprint/02_ColorSensorCasing_Print.md) — S4 casing manufacturing and validation.
- [**Pixy2.1 Case Print**](./models/3dprint/03_PixyCase_Print.md) — Camera-case manufacturing and validation.
- [**ColorSensorCasing.stl**](./models/3dprint/ColorSensorCasing.stl) — Printable Color Sensor casing.
- [**PIXY_Case1.stl**](./models/3dprint/PIXY_Case1.stl) — First component of the Pixy2.1 case.
- [**PIXY_Case2.stl**](./models/3dprint/PIXY_Case2.stl) — Second component of the Pixy2.1 case.

## Evolution Files

The evolution files show how Piolín changed from early EV3 prototypes to the
current architecture.

- [**Phase 1**](./models/evolution/Phase1.md) — Initial EV3 prototype and foundational lessons.
- [**Phase 2**](./models/evolution/Phase2.md) — Mechanical and navigation development.
- [**Phase 3**](./models/evolution/Phase3.md) — Sensor, vision, and control experimentation.
- [**Phase 4**](./models/evolution/phase4.md) — Current competition architecture.

## Team and Timeline

- [**Official Team Picture**](./t-gtku/officialpictureptech.md) — Formal PiolínTech team image.
- [**Funny Team Picture**](./t-gtku/funnypicture.md) — Informal team photograph.
- [**Project Timeline**](./t-gtku/timeline.md) — Chronological development history.

## Videos

- [**Video Index**](./videos/links.md) — Central list of autonomous demonstrations and test videos.
- [**Open Challenge Video**](https://www.youtube.com/watch?v=JROB39Az-Ys) — Open-round autonomous demonstration.
- [**Obstacle Challenge Video**](https://youtu.be/Tlw_LM0b6WE) — Obstacle-round autonomous demonstration.

---

# V4 Photographic Evidence

## Current Vehicle Views

The V4 photo directory is the main photographic reference for the current
robot. It contains overall vehicle views as well as close-ups of the chassis,
steering, drivetrain, sensors, controller, battery, wiring, and Pixy
detections.

- [**Front View**](./v-photos/v4/Piolin_open_front.jpeg)
- [**Rear View**](./v-photos/v4/piolin_open_rear.jpg)
- [**Left View**](./v-photos/v4/piolin_open_left.jpg)
- [**Right View**](./v-photos/v4/piolin_open_right.jpg)
- [**Top View**](./v-photos/v4/piolin_open_top.jpg)
- [**Bottom View**](./v-photos/v4/piolin_bottom.jpg)
- [**Open Isometric View**](./v-photos/v4/piolin_open_isometric.jpg)
- [**Obstacle Isometric View**](./v-photos/v4/piolin_obstacle_isometric.jpg)

## Mechanical Evidence

- [**Ackermann Front View**](./v-photos/v4/ackermann_front.jpg)
- [**Ackermann Angles**](./v-photos/v4/ackermann_angles.jpg)
- [**Ackermann Center**](./v-photos/v4/ackermann_center.jpg)
- [**Left Steering Lock**](./v-photos/v4/ackermann_left_lock.jpg)
- [**Right Steering Lock**](./v-photos/v4/ackermann_right_lock.jpg)
- [**Rear Drivetrain Top**](./v-photos/v4/rear_drivetrain_top.jpg)
- [**Rear Drivetrain Bottom**](./v-photos/v4/rear_drivetrain_bottom.jpg)
- [**Steering Motion**](./v-photos/v4/steering_motion.gif)

## Sensor Evidence

- [**S2 Left Ultrasonic**](./v-photos/v4/ultrasonic_left_s2.jpg)
- [**S3 Right Ultrasonic**](./v-photos/v4/ultrasonic_right_s3.jpg)
- [**Ultrasonic Pair**](./v-photos/v4/ultrasonic_pair_top.jpg)
- [**S4 Installed**](./v-photos/v4/color_sensor_s4_installed.jpg)
- [**Color Sensor Casing**](./v-photos/v4/color_sensor_casing.jpg)
- [**Blue Mark**](./v-photos/v4/color_sensor_blue_mark.jpg)
- [**Orange Mark**](./v-photos/v4/color_sensor_orange_mark.jpg)
- [**Open Gyro**](./v-photos/v4/s1_open_gyro.jpg)
- [**Obstacle Pixy2.1**](./v-photos/v4/s1_obstacle_pixy.jpg)

## Vision Evidence

- [**Pixy2.1 Front**](./v-photos/v4/pixy21_front.jpg)
- [**Pixy2.1 Side**](./v-photos/v4/pixy21_side.jpg)
- [**Pixy2.1 Top**](./v-photos/v4/pixy21_top.jpg)
- [**Pixy2.1 S1 Connection**](./v-photos/v4/pixy21_s1_connection.jpg)
- [**Red Detection**](./v-photos/v4/pixy21_red_detection.jpg)
- [**Green Detection**](./v-photos/v4/pixy21_green_detection.jpg)
- [**Pink Parking Detection**](./v-photos/v4/pixy21_parking_detection.jpg)

## Wiring Evidence

- [**Open Wiring**](./v-photos/v4/wiring_open.jpg)
- [**Obstacle Wiring**](./v-photos/v4/wiring_obstacle.jpg)
- [**EV3 Motor Ports**](./v-photos/v4/ev3_motor_ports.jpg)
- [**EV3 Sensor Ports**](./v-photos/v4/ev3_sensor_ports.jpg)
- [**EV3 Battery 45501**](./v-photos/v4/ev3_battery_45501.jpg)

---

# Documentation Coverage

## WRO Engineering Documentation Map

The repository is organized so each major engineering area has both a
high-level explanation and direct technical evidence.

| Engineering Area | Main Evidence |
| --- | --- |
| **Mobility & Mechanical Design** | Mobility documentation, Ackermann analysis, drivetrain documentation, torque reasoning, and V4 mechanical photographs |
| **Power & Sensor Architecture** | Power and sensor documentation, component files, wiring, port mapping, current schemes, and sensor photographs |
| **Software Architecture & Obstacle Strategy** | Software documentation, Round 1 and Round 2 source code, vision flow, state logic, control arbitration, and obstacle strategy |
| **Systems Thinking & Engineering Decisions** | Engineering process, decision log, trade-offs, risks, rejected ideas, evolution documents, and project timeline |
| **Reproducibility & GitHub Quality** | BOM, wiring, software setup, calibration, testing, troubleshooting, STL files, photographs, videos, and clickable navigation |

## Evidence Philosophy

The README provides the project story and quick navigation, while the linked
files provide the deeper engineering detail. This prevents the main page from
becoming a disconnected collection of every calculation and experiment while
still allowing a judge to reach the supporting evidence directly.

The repository also separates current architecture from legacy development.
This is important because historical experimentation is valuable evidence only
when it is clearly identified as historical rather than presented as part of
the current competition robot.

---

# Final Engineering Perspective

## What Piolín Represents

Piolín is not defined by one sensor, one controller, or one successful run. Its
autonomous behavior comes from the interaction between mechanical geometry,
sensor placement, perception, navigation states, control logic, and motor
actuation.

The current architecture gives every major component a clear responsibility.
Motor A provides rear propulsion. Motor B operates the Ackermann steering
mechanism. S2 and S3 observe lateral geometry. S4 detects physical course
landmarks. S1 provides either heading information through the Gyro Sensor or
visual perception through Pixy2.1 depending on the challenge.

## How We Evaluate Success

The most important change throughout PiolínTech's development has been the way
the team evaluates a successful result. Instead of only asking whether the
robot completed a maneuver, we ask why it worked, whether the behavior can be
repeated, what changes when the initial conditions are different, and which
subsystem fails first when something goes wrong.

That process is what transformed the early prototypes into the current Piolín
and continues to guide the remaining calibration work for WRO Future Engineers
2026.

<p align="center">
  
</p>

<p align="center">
  <b>Designed · Built · Programmed · Tested · Documented by PiolínTech</b>
</p>

---

# Quick Evidence Checklist

## Mechanical & Sensor Evidence

Current V4 photographs, Ackermann documentation, drivetrain evidence, S2-left / S3-right sensing, S4 floor sensing, and the round-specific S1 configuration are all directly linked in this README.

## Software & Reproducibility Evidence

Round-specific source code, code explanations, flowcharts, BOM, wiring, setup, calibration, testing, troubleshooting, STL files, photographs, and videos are directly accessible.

## Engineering Evidence

Decision logs, trade-offs, risks, rejected approaches, project history, and evolution files document how the current architecture was reached.

<p align="center"><b>PiolínTech · WRO Future Engineers 2026</b></p>

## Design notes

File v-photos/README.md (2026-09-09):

# Electromechanical Evolution and Visual Documentation

This section provides a visual record of the physical evolution of **Piolín** throughout its development for WRO Future Engineers. Each group of images presents the robot from multiple viewpoints so that changes in chassis organization, steering geometry, sensor placement, controller position, drivetrain layout, and overall packaging can be compared between generations.

The purpose of these views is not simply to show how the robot looked at different moments. They document how the electromechanical architecture evolved as testing exposed new requirements. Changes to the position of a sensor, the steering structure, the EV3 Brick, or the drivetrain can significantly affect weight distribution, cable routing, turning behavior, sensing geometry, and software calibration. For this reason, PiolínTech treats the physical configuration of the robot as part of the autonomous system rather than as an independent mechanical shell.

The earlier configurations shown below are preserved as engineering history. Some contain arrangements that were later modified or abandoned, while others introduced mechanical ideas that continued into later versions. **V4 represents the current Piolín architecture** and should therefore be used as the main physical reference when comparing the current documentation with older designs.

---

## PARTIALLY LEGO

The **Partially LEGO** configuration represents an intermediate stage in Piolín's physical development. At this point, the team was still experimenting with the organization of the chassis and the integration of the different mechanical and sensing elements. The robot already reflected a more deliberate vehicle-oriented layout than the earliest prototypes, but several areas of the design were still being evaluated and modified through physical testing.

This stage was particularly useful for understanding how the position of major components influenced the available space for steering, sensing, wiring, and drivetrain mechanisms. Rather than considering each component independently, the team began evaluating how the complete arrangement affected the robot's ability to navigate the WRO track.

| Front View | Back View | Left View |
| :---: | :---: | :---: |
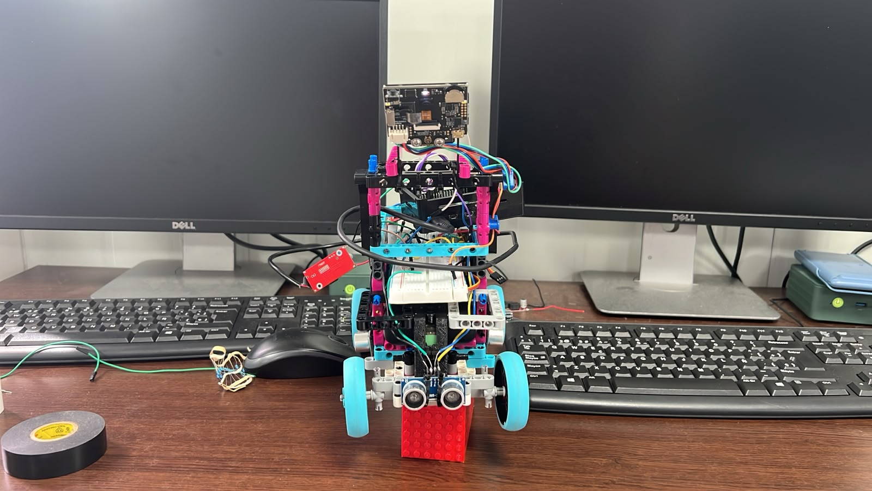
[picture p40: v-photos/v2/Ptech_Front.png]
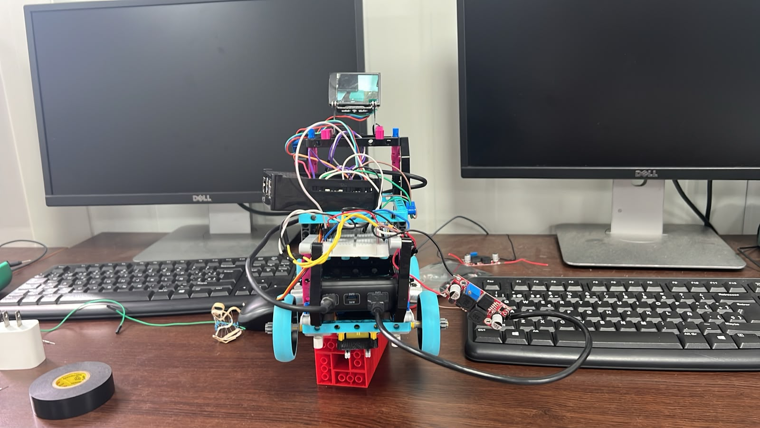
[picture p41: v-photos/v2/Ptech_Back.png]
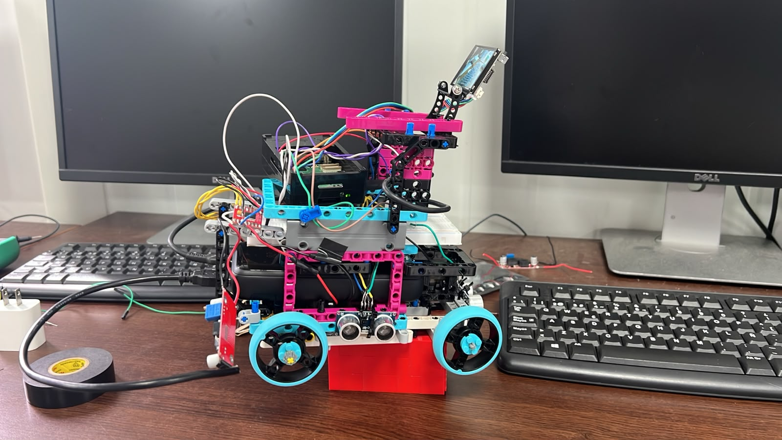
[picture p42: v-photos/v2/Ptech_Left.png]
|  |  |  |
| **Right View** | **Top View** | **Bottom View** |
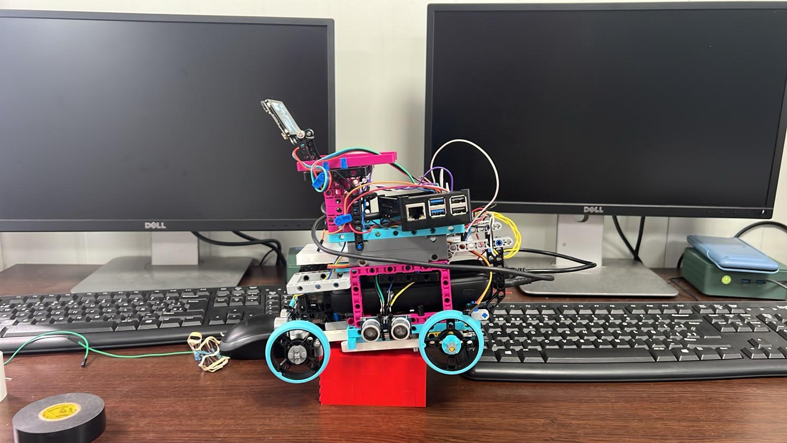
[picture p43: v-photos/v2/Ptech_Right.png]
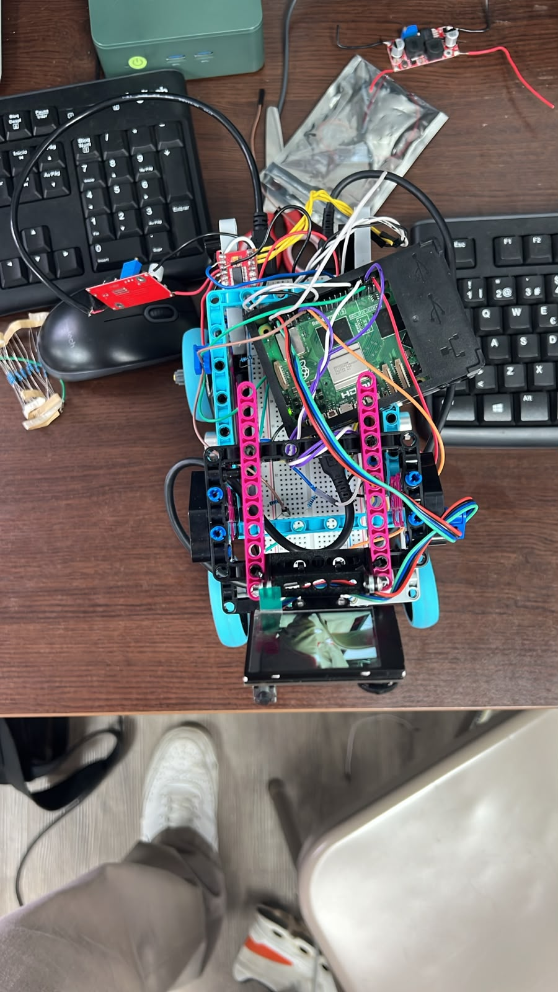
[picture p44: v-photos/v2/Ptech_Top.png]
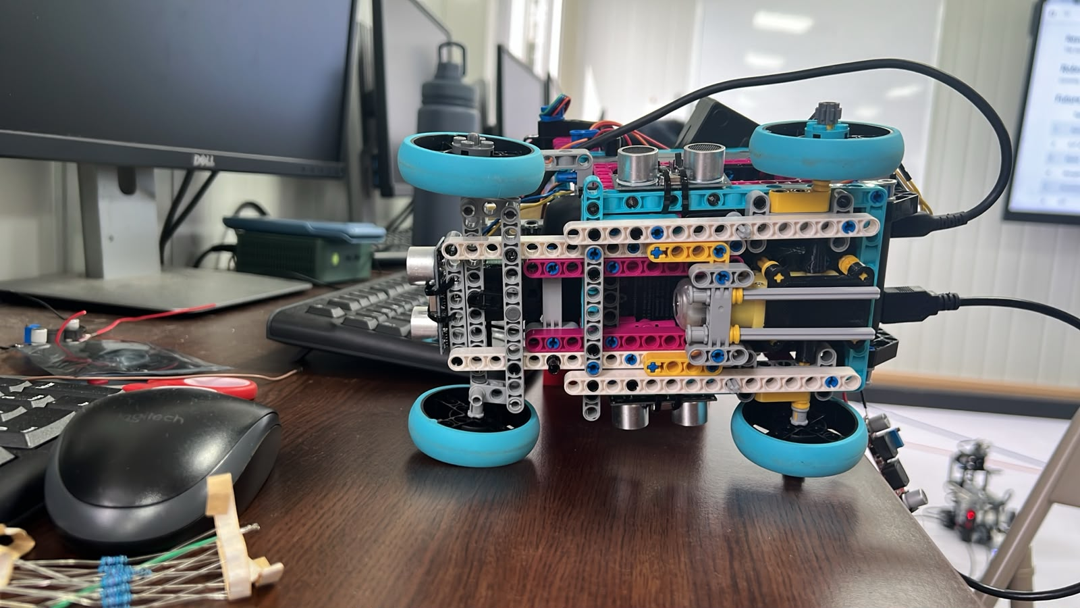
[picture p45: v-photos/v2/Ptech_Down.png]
|  |  |  |

The six views make it possible to inspect the relationship between the vehicle footprint, wheel placement, structural members, and internal component organization. This configuration remains documented because it represents part of the iterative process that eventually led to the more organized layouts used in later versions.

---

## COMPLETE LEGO

The **Complete LEGO** configuration represents another important development stage in which the vehicle architecture was explored using a highly integrated LEGO-based structure. This version allowed PiolínTech to evaluate how much of the vehicle could be constructed within the LEGO ecosystem while still maintaining the mechanical characteristics required for Future Engineers.

One of the main benefits of this stage was the ability to rapidly reposition components and rebuild structural sections between tests. This made it possible to experiment with different chassis layouts without committing immediately to a single configuration. The resulting observations helped the team understand where additional rigidity, improved sensor placement, or different mechanical arrangements were necessary.

| **Front View** | **Back View** | **Left View** |
| :---: | :---: | :---: |
| Front view of Complete LEGO Piolín | Back view of Complete LEGO Piolín | Left view of Complete LEGO Piolín |
| **Right View** | **Top View** | **Bottom View** |
| Right view of Complete LEGO Piolín | Top view of Complete LEGO Piolín | Bottom view of Complete LEGO Piolín |

This version is useful as a visual reference for understanding how PiolínTech gradually moved from rapid structural experimentation toward a more deliberate electromechanical arrangement. Several decisions that later became permanent were shaped by observations made while working with these earlier LEGO structures.

---

## V3 LEGO

The **V3 LEGO** generation represents a much more mature stage of the robot's mechanical development. By this point, Piolín had evolved beyond the basic question of whether the robot could move autonomously. The focus increasingly shifted toward making the vehicle easier to control, easier to reproduce, and more predictable across repeated track runs.

The chassis organization became more closely connected to the requirements of Ackermann steering, rear propulsion, lateral sensing, and autonomous course navigation. V3 also became an important experimental platform for evaluating different sensor arrangements and vision concepts before the final round-specific architecture was selected.

| Front View | Back View | Left View |
| :---: | :---: | :---: |
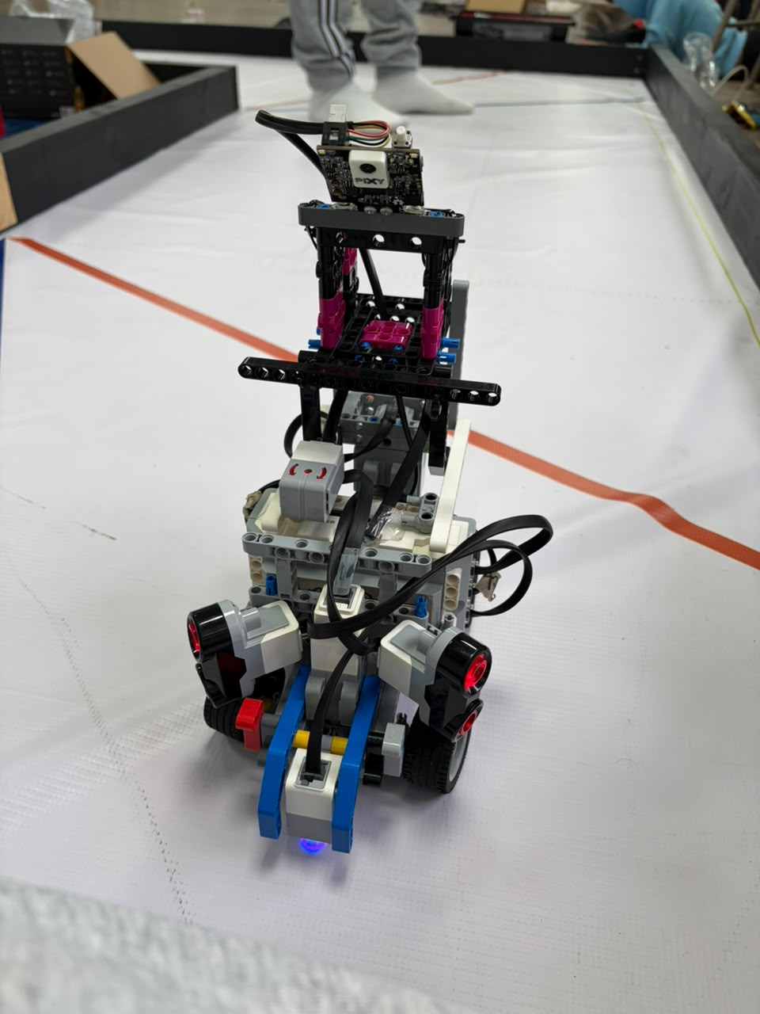
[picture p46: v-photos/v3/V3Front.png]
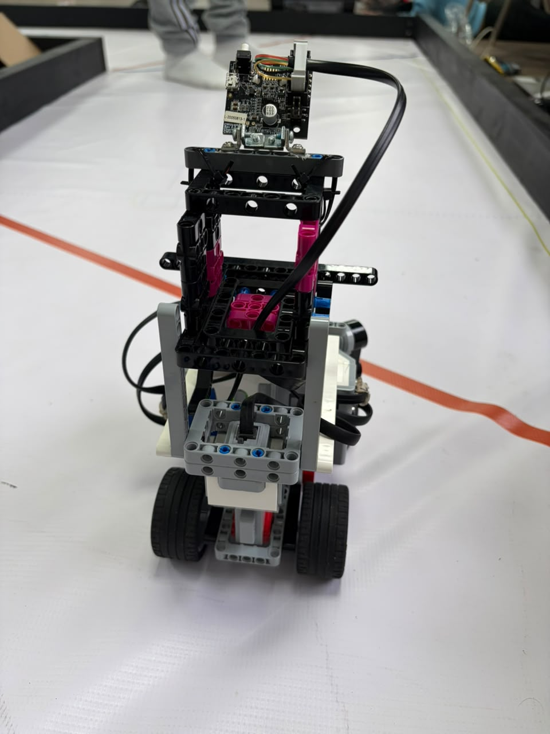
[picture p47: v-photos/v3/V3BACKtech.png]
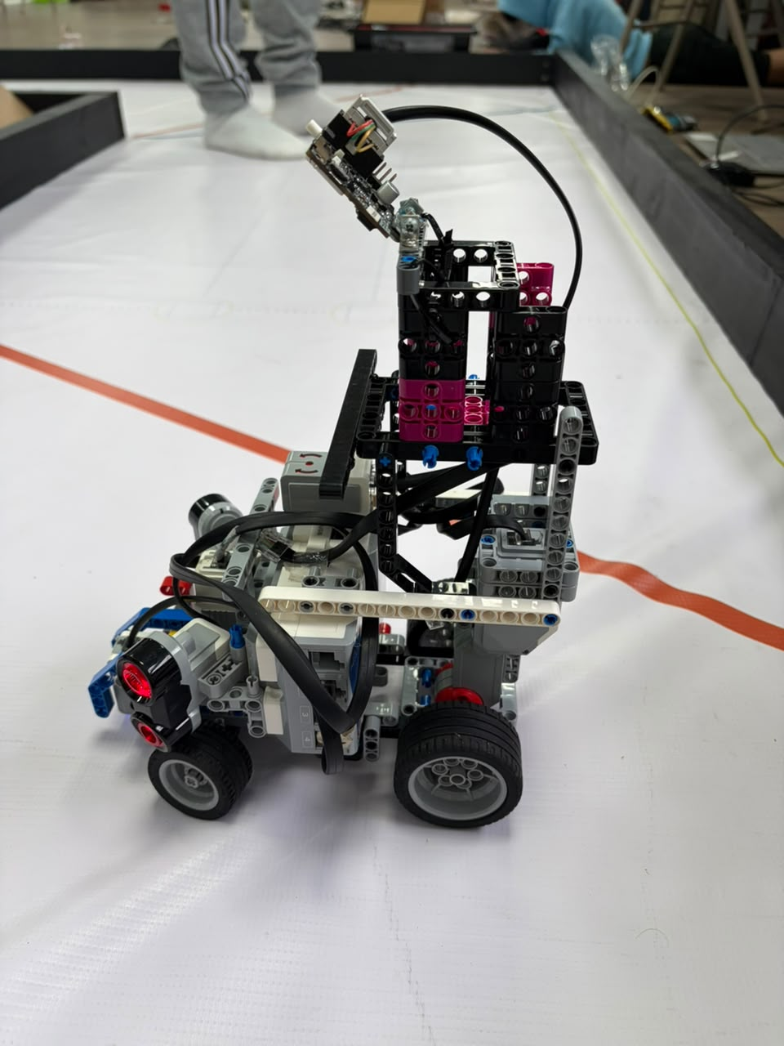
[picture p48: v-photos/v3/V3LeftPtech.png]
|  |  |  |
| **Right View** | **Top View** | **Bottom View** |
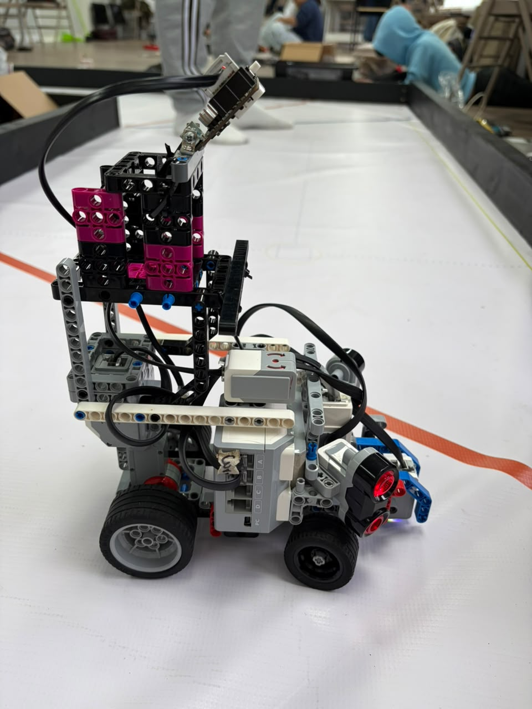
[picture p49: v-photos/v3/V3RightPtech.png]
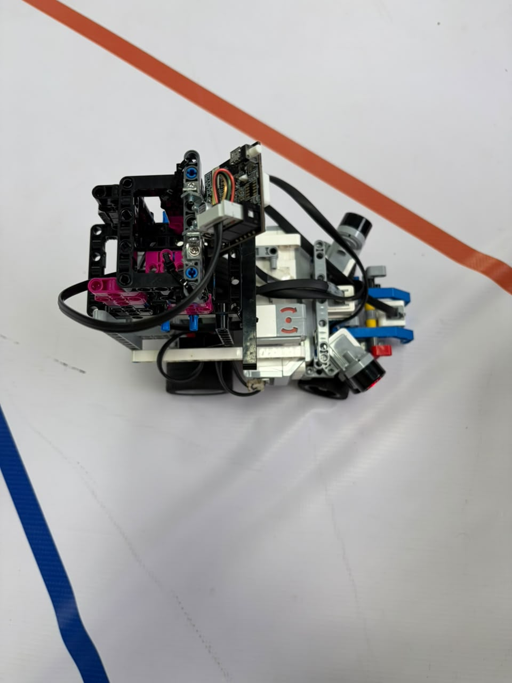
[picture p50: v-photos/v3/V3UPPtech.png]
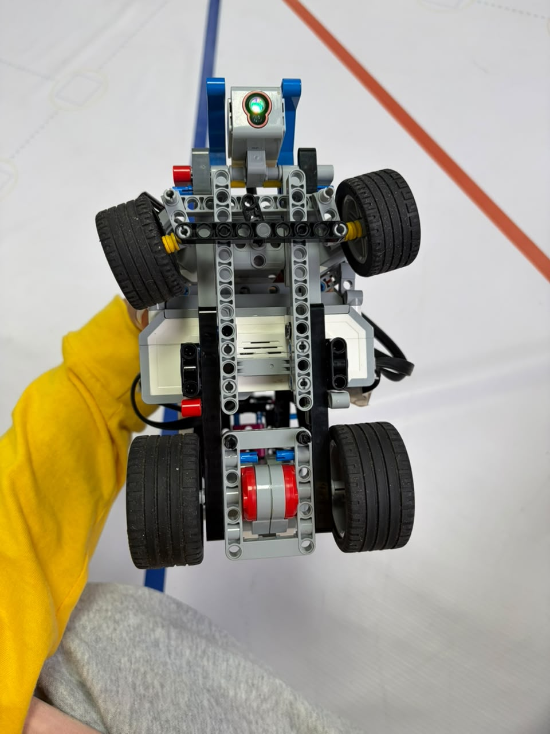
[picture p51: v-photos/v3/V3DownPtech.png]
|  |  |  |

The different views show how the robot was becoming increasingly organized around a vehicle-specific architecture rather than a general-purpose EV3 chassis. This generation played an important role in the experiments that later determined which sensors should remain permanent and which should become round-specific.

V3 should therefore be understood as a **development platform**, not as the current competition configuration. Several of the ideas tested here were later retained, while others were simplified or replaced in V4.

---

## V4 — CURRENT PIOLÍN

**V4 is the current Piolín architecture for WRO Future Engineers 2026.** It represents the consolidation of the mechanical, sensing, and control decisions obtained through the previous development phases.

The current platform retains the LEGO MINDSTORMS EV3 Brick as the central controller and uses two clearly separated motor functions. **Motor A**, an EV3 Large Motor, provides rear propulsion, while **Motor B**, an EV3 Medium Motor, controls the front Ackermann-style steering mechanism. This separation between propulsion and steering is one of the defining characteristics of the current vehicle architecture.

The sensor arrangement was also simplified compared with several earlier experiments. Piolín now uses two permanent lateral EV3 Ultrasonic Sensors: **S2 is always the physical left ultrasonic sensor and S3 is always the physical right ultrasonic sensor**. The downward-facing EV3 Color Sensor remains on **S4** and is used to observe the Blue and Orange floor landmarks that contribute to direction detection and course progression.

S1 is intentionally round-specific. During the Open Challenge, an EV3 Gyro Sensor occupies S1 and provides heading and rotation information. During the Obstacle Challenge, the gyro is removed and Pixy2.1 occupies S1 to provide visual information about Red, Green, and Pink targets. These two devices are not installed simultaneously in the current competition architecture.

### V4 — Current Open Configuration

| Front View | Rear View | Left View |
| :---: | :---: | :---: |
| Front view of Piolín V4 | Rear view of Piolín V4 | Left view of Piolín V4 |
| **Right View** | **Top View** | **Bottom View** |
| Right view of Piolín V4 | Top view of Piolín V4 | Bottom view of Piolín V4 |

These six views provide the main physical reference for the current Open Challenge robot. They show the actual relationship between the EV3 Brick, drivetrain, steering structure, lateral ultrasonic sensors, downward Color Sensor, wheels, structural members, and cable routing.

The Open photographs are especially useful because they document the configuration in which S1 is occupied by the Gyro Sensor. The same common mechanical platform is retained during the Obstacle Challenge, but S1 is instead occupied by Pixy2.1.

---

### V4 Mechanical Architecture

The most important mechanical characteristic of V4 is the clear separation between propulsion and steering. The rear of the robot is driven by Motor A, while Motor B operates the front Ackermann steering linkage. This allows the software to treat longitudinal progression and steering curvature as separate control variables while preserving the behavior of a car-like vehicle.

The Ackermann mechanism also means that Piolín cannot be modeled as a differential-drive robot. The robot follows curved trajectories produced by steering the front wheels while the vehicle moves forward or backward. As a result, steering geometry, vehicle speed, wheel alignment, and the timing of corrections all directly influence the physical path.

The current chassis also provides defined locations for the sensors instead of treating sensor mounting as temporary. This is particularly important for the ultrasonic sensors, because changing their physical position or orientation changes the geometry being measured and can invalidate previously calibrated navigation parameters.

---

### V4 Sensor Placement

The two ultrasonic sensors are mounted laterally so that the software can observe Piolín's relationship with the surrounding track boundaries. Their physical identities remain constant: S2 is left and S3 is right. Depending on whether Piolín travels clockwise or counterclockwise, the software may interpret one sensor as the inner sensor and the other as the outer sensor, but their physical names and ports never change.

The Color Sensor is mounted downward on S4. Its physical environment is supported by a custom 3D-printed casing designed to reduce uncontrolled light entering the immediate sensing area. Because changes to the casing or sensor height can affect reflection and RGB measurements, the Color Sensor is recalibrated whenever its physical installation changes significantly.

During the Obstacle Challenge, Pixy2.1 is installed as the forward vision sensor and uses a custom two-part 3D-printed casing. The casing contributes to mechanical support and repeatable camera positioning while preserving the required field of view. Because the physical orientation of the camera affects the position and apparent size of detected objects, camera mounting is treated as part of the vision calibration.

---

### V4 Electromechanical Integration

V4 represents a shift away from viewing the robot as a collection of independent hardware components. Instead, PiolínTech treats mechanical geometry, sensors, actuators, and software as parts of one closed-loop electromechanical system.

A change to the steering linkage can alter the curvature produced by Motor B. A change to ultrasonic positioning can alter the wall measurements received by the navigation controller. Moving Pixy2.1 can change the image coordinates used by the perception system, and modifying the Color Sensor casing can alter the optical values used for floor classification.

For this reason, mechanical modifications are followed by sensor and software verification rather than assuming that previous calibration remains valid.

---

## Evolution Across the Four Visual Generations

The visual progression from the earlier configurations to V4 demonstrates how Piolín gradually became more organized around clearly defined subsystem responsibilities. Early versions were primarily useful for rapid experimentation and discovering mechanical limitations. Later versions increasingly focused on repeatability, controlled sensor geometry, steering consistency, and simpler hardware integration.

| Engineering Area | Earlier Prototypes | V3 | V4 — Current |
| :--- | :--- | :--- | :--- |
| Central controller | EV3-based experimentation | EV3 | **EV3** |
| Vehicle structure | Rapidly changing layouts | More mature vehicle layout | **Current competition chassis** |
| Propulsion | Experimental arrangements | Dedicated drive development | **Motor A rear propulsion** |
| Steering | Evolving mechanisms | Ackermann refinement | **Motor B Ackermann steering** |
| Ultrasonic sensing | Multiple arrangements tested | Sensor-role experimentation | **S2 LEFT + S3 RIGHT** |
| Floor sensing | Developing | S4 integration and testing | **S4 downward Color Sensor** |
| Open orientation | Experimental | Gyro testing | **S1 Gyro** |
| Obstacle vision | Experimental | Multiple vision approaches tested | **S1 Pixy2.1** |
| Custom 3D printing | Limited / developing | Experimental use | **Sensor casings integrated into current architecture** |
| Software relationship | More reactive | Increasing subsystem organization | **Layered sensing, state logic, and control** |
| Status | Historical development | Legacy development platform | **CURRENT** |

The table is intentionally qualitative. It documents architectural evolution without assigning performance values that were not formally measured under controlled conditions.

---

## Why V4 Is the Current Reference

V4 does not represent a completely unrelated robot built after the previous versions. It is the result of decisions made while testing those versions. Ackermann steering was refined through repeated mechanical iterations. Sensor layouts were changed as the team learned what geometric information was actually useful. Vision systems were tested before Pixy2.1 was selected for the current Obstacle Challenge configuration, and the use of S1 became round-specific after experimenting with competing sensing requirements.

The result is a robot with a much clearer physical architecture. Motor A handles propulsion, Motor B handles steering, S2 and S3 provide lateral geometry, S4 provides floor information, and S1 provides the specialized information needed by the selected round.

This clarity also improves software development because a failure can be traced back to a specific physical subsystem rather than being hidden inside an ambiguous hardware arrangement.

---

## Visual Documentation as Engineering Evidence

These six-view records are maintained because physical configuration is part of the reproducibility of an autonomous robot. Knowing which program was used is not sufficient if the sensors, steering mechanism, or drivetrain are installed differently.

The images therefore provide evidence of component placement and overall vehicle organization at different development stages. They also make it possible to compare older configurations with the current robot and understand which physical changes correspond to decisions documented elsewhere in the repository.

For current reproduction and evaluation, **V4 should be treated as the authoritative physical reference**. Earlier views remain available to document the engineering path that produced it.

---

## Current Physical Reference

The current V4 architecture can be summarized as follows:

| Component | Current Role |
| :--- | :--- |
| LEGO MINDSTORMS EV3 Brick | Main controller |
| Motor A — EV3 Large Motor | Rear propulsion |
| Motor B — EV3 Medium Motor | Ackermann steering |
| S2 — EV3 Ultrasonic Sensor | Left lateral sensing |
| S3 — EV3 Ultrasonic Sensor | Right lateral sensing |
| S4 — EV3 Color Sensor | Downward floor sensing |
| S1 — EV3 Gyro Sensor | Open Challenge heading and rotation |
| S1 — Pixy2.1 | Obstacle Challenge vision |
| EV3 Rechargeable Battery 45501 | Main power source |
| `ColorSensorCasing.stl` | Color Sensor physical/optical casing |
| `PIXY_Case1.stl` + `PIXY_Case2.stl` | Pixy2.1 casing assembly |

The Gyro Sensor and Pixy2.1 are **round-specific alternatives on S1 and are not installed simultaneously**.

---

## Conclusion

The electromechanical evolution of Piolín reflects a gradual transition from experimental physical layouts toward a vehicle in which component placement and subsystem responsibilities are deliberately defined. Earlier configurations were essential for exposing problems related to mechanics, steering, sensing, packaging, and integration, while later versions increasingly transformed those observations into repeatable design decisions.

V4 represents the current result of that process. Its importance does not come from claiming that every mechanical or software parameter is permanently final, but from having a stable architecture in which propulsion, Ackermann steering, lateral sensing, floor sensing, round-specific orientation or vision, and EV3 control have clearly defined roles. This physical architecture now provides the baseline on which PiolínTech continues to calibrate and improve autonomous performance.

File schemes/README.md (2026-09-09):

# PiolínTech Technical Schemes

The `schemes/` directory contains the main **electrical, hardware, port-mapping, and system-layout diagrams** used to document Piolín for WRO Future Engineers 2026.

These diagrams complement the rest of the repository by showing how the robot is physically and technically organized.

The purpose of this directory is different from `embed/`:

```text
schemes/
→ hardware
→ electrical architecture
→ EV3 connections
→ physical system organization
```

while:

```text
embed/
→ software architecture
→ state machines
→ control logic
→ perception pipelines
→ engineering processes
```

Together, both directories provide a complete representation of Piolín from hardware connection to autonomous behavior.

---

# Directory Structure

```text
schemes/
│
├── 01_EV3Kicad.png
├── 02_EV3PortMap.png
├── 03_OverallScheme.png
├── 04_OpenConfiguration.png
└── README.md
```

The four diagrams are ordered from the EV3 electronics level toward the complete robot configuration.

---

# 01 — EV3 KiCad Reference

## `01_EV3Kicad.png`

This image contains the **KiCad-based EV3 electrical reference** used as part of PiolínTech's hardware documentation.

It provides a more technical electronics-level view than the simplified diagrams used elsewhere in the repository.

Its purpose is to support understanding of the EV3 as the central hardware platform around which Piolín is built.

<div align="center">

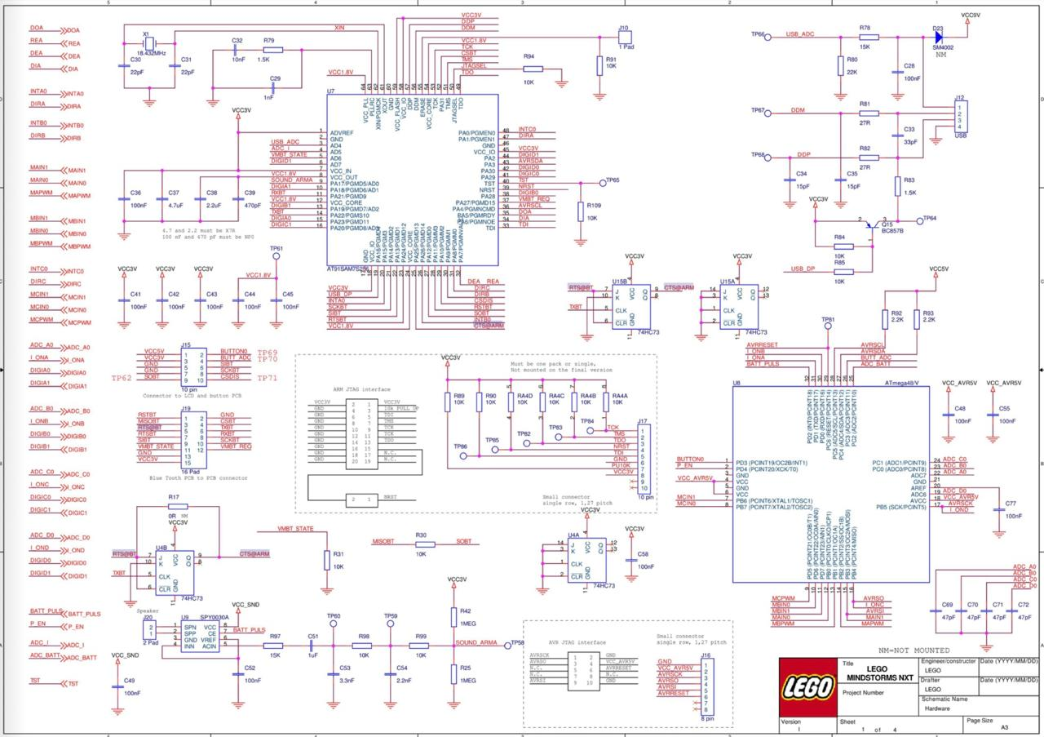
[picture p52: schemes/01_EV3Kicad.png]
PiolínTech EV3 KiCad electrical reference


<br>

<sub><b>Figure 1.</b> KiCad-based EV3 electrical reference used in PiolínTech's technical documentation.</sub>

</div>

Piolín continues to use the LEGO MINDSTORMS EV3 Brick as its main controller in the current architecture.

The robot does not use a Raspberry Pi or an external general-purpose computer as its autonomous-control core.

---

# 02 — EV3 Port Map

## `02_EV3PortMap.png`

The EV3 Port Map provides the clearest reference for Piolín's **motor and sensor assignments**.

<div align="center">

Piolín EV3 port mapping

<br>

<sub><b>Figure 2.</b> Piolín's EV3 sensor and motor port mapping.</sub>

</div>

The permanent motor assignments are:

```text
PORT A
→ EV3 Large Motor
→ rear propulsion
```

```text
PORT B
→ EV3 Medium Motor
→ Ackermann steering
```

Ports C and D are not part of the current primary motor architecture.

The permanent common sensor assignments are:

```text
S2
→ LEFT EV3 Ultrasonic Sensor
```

```text
S3
→ RIGHT EV3 Ultrasonic Sensor
```

```text
S4
→ downward-facing EV3 Color Sensor
```

S1 is **round-specific**.

### Open Challenge

```text
S1
→ EV3 Gyro Sensor
```

### Obstacle Challenge

```text
S1
→ Pixy2.1
```

Therefore:

> **The Gyro Sensor and Pixy2.1 are not installed simultaneously in the current competition architecture.**

---

# 03 — Overall Robot Scheme

## `03_OverallScheme.png`

The Overall Scheme provides a broader technical representation of Piolín as a complete vehicle.

<div align="center">

Piolín overall technical scheme

<br>

<sub><b>Figure 3.</b> Overall technical scheme of Piolín's current mechanical and sensing architecture.</sub>

</div>

While the Port Map focuses primarily on:

```text
WHAT CONNECTS WHERE
```

the Overall Scheme focuses on:

```text
WHERE THE COMPONENTS ARE

WHAT THEY DO

HOW THE VEHICLE IS ORGANIZED
```

The major physical systems represented are:

```text
EV3 Brick
→ central controller

Motor A
→ rear propulsion

Motor B
→ front Ackermann steering

S2
→ left lateral sensing

S3
→ right lateral sensing

S4
→ floor sensing

S1
→ round-specific sensing
```

This diagram helps connect the electrical architecture with the actual physical robot.

---

# 04 — Open Challenge Configuration

## `04_OpenConfiguration.png`

This diagram documents Piolín's current **Open Challenge sensor configuration**.

<div align="center">

Piolín Open Challenge configuration

<br>

<sub><b>Figure 4.</b> Piolín's Open Challenge configuration using the EV3 Gyro Sensor on S1.</sub>

</div>

The Open configuration is:

```text
MOTOR A
→ EV3 Large Motor
→ rear propulsion

MOTOR B
→ EV3 Medium Motor
→ Ackermann steering

S1
→ EV3 Gyro Sensor

S2
→ LEFT EV3 Ultrasonic Sensor

S3
→ RIGHT EV3 Ultrasonic Sensor

S4
→ EV3 Color Sensor
→ downward-facing
```

Each sensor has a different responsibility.

### S1 — Gyro

```text
heading information

vehicle rotation

corner support

drift correction
```

### S2 + S3 — Lateral Ultrasonics

```text
course geometry

wall relationship

lateral-position information

safety context
```

### S4 — Color Sensor

```text
Blue course markings

Orange course markings

initial direction

course-event progression
```

The Open configuration therefore separates:

```text
LATERAL POSITION
→ S2 + S3
```

```text
ORIENTATION
→ S1 Gyro
```

```text
COURSE LANDMARKS
→ S4 Color Sensor
```

---

# Hardware Architecture Summary

The current common hardware architecture can be represented as:

```text
                    LEGO EV3 BRICK
                          │
          ┌───────────────┼───────────────┐
          │               │               │
          ▼               ▼               ▼
       MOTOR A          MOTOR B         SENSORS
       Large            Medium             │
          │               │                │
          ▼               ▼        ┌───────┼───────┐
        REAR          ACKERMANN      │       │       │
     PROPULSION       STEERING      S2      S3      S4
                                    LEFT    RIGHT   COLOR
                                     US      US
                                             
                          S1
                           │
                 ┌─────────┴─────────┐
                 ▼                   ▼
               GYRO                PIXY2.1
               OPEN               OBSTACLES
```

The architecture deliberately preserves a stable common platform while changing only the sensing capability required by each round.

---

# Scheme Hierarchy

Each image answers a different engineering question.

| Scheme | Main Question |
|---|---|
| `01_EV3Kicad.png` | What does the EV3 electrical reference look like at a more technical level? |
| `02_EV3PortMap.png` | Which device is connected to each EV3 port? |
| `03_OverallScheme.png` | How are the major systems physically and technically organized on Piolín? |
| `04_OpenConfiguration.png` | How is Piolín specifically configured for the Open Challenge? |

They should therefore be read as complementary diagrams rather than duplicates.

The progression is:

```text
EV3 ELECTRONICS
      ↓
PORT ASSIGNMENTS
      ↓
COMPLETE ROBOT
      ↓
ROUND-SPECIFIC CONFIGURATION
```

---

# Relationship with Other Repository Sections

The schemes should be interpreted together with the rest of PiolínTech's documentation.

## Schemes

```text
schemes/
→ electrical and physical architecture
```

## Embedded diagrams

```text
embed/
→ software and control architecture
```

Important visual software references include:

```text
Navigation State Machine

Pixy Vision Processing

Control Arbitration

Obstacle Strategy

Color Event Processing

Parking State Machine

System Architecture
```

## Robot photographs

```text
v-photos/v4/
→ photographic evidence of the real robot
```

## 3D models

```text
models/3dprint/
→ custom manufactured sensor components
```

## Evolution

```text
models/evolution/
→ development history from Phase 1 to Phase 4
```

This organization separates:

```text
SCHEMATIC EVIDENCE

SOFTWARE LOGIC

PHYSICAL EVIDENCE

MANUFACTURING

ENGINEERING EVOLUTION
```

while keeping the sections connected.

---

# Current Port Reference

For quick reference:

| Port | Current Device | Function | Configuration |
|---|---|---|---|
| A | EV3 Large Motor | Rear propulsion | Both rounds |
| B | EV3 Medium Motor | Ackermann steering | Both rounds |
| S1 | EV3 Gyro Sensor | Heading / rotation | Open |
| S1 | Pixy2.1 | Vision | Obstacles |
| S2 | EV3 Ultrasonic Sensor | Left lateral geometry | Both rounds |
| S3 | EV3 Ultrasonic Sensor | Right lateral geometry | Both rounds |
| S4 | EV3 Color Sensor | Floor landmarks | Both rounds |

The physical naming convention is always:

```text
S2 = LEFT

S3 = RIGHT
```

The software may interpret one as the:

```text
inner sensor
```

and the other as the:

```text
outer sensor
```

depending on course direction, but their physical identities never change.

---

# Documentation Accuracy

These schemes are intended as **technical documentation diagrams**, not manufacturing drawings with guaranteed scale.

Where dimensions or physical relationships require exact verification, the real robot and measured engineering documentation should take priority over approximate graphical representations.

Likewise, the diagrams should not be interpreted as evidence that every depicted software behavior is already fully calibrated.

The current competition architecture is documented separately from ongoing parameter tuning.

This distinction allows the repository to accurately represent:

```text
CURRENT HARDWARE ARCHITECTURE
```

while still acknowledging:

```text
ONGOING SOFTWARE CALIBRATION
```

---

# Final Scheme Overview

The complete `schemes/` section can be summarized as:

```text
01_EV3Kicad.png
      ↓
ELECTRONICS REFERENCE

02_EV3PortMap.png
      ↓
PORT CONNECTIONS

03_OverallScheme.png
      ↓
PHYSICAL + TECHNICAL ROBOT LAYOUT

04_OpenConfiguration.png
      ↓
CURRENT OPEN ROUND CONFIGURATION
```

Together, these diagrams provide a compact visual explanation of the hardware foundation on which Piolín's autonomous software operates.

The central principle of this section is:

> **Piolín's technical schemes document the path from the EV3 hardware platform to the physical vehicle configuration, making the robot's connections, sensor roles, motor assignments, and Open Challenge architecture understandable without requiring the reader to infer them from source code alone.**

---

<div align="center">

### [← Back to PiolínTech Main README](../README.md)

</div>

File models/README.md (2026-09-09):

# Evolution of Piolín

This directory documents the engineering evolution of **Piolín**, PiolínTech's autonomous vehicle for the WRO Future Engineers 2026 competition.

Piolín did not evolve through a single complete redesign.

Instead, the robot developed through a sequence of mechanical, sensing, vision, and software iterations in which each prototype exposed limitations that influenced the next engineering decision.

One important fact remained constant throughout the project:

> **Piolín has always been developed around the LEGO MINDSTORMS EV3 platform.**

The evolution was therefore not:

```text
EV3
→ different computer
→ completely different robot
```

It was:

```text
EV3 INITIAL PROTOTYPE
        ↓
MECHANICAL + NAVIGATION DEVELOPMENT
        ↓
SENSOR + VISION + CONTROL EXPERIMENTATION
        ↓
CURRENT EV3 COMPETITION ARCHITECTURE
```

Earlier phases are preserved as engineering evidence.

**Phase 4 represents Piolín's current architecture.**

---

# Development Timeline

```mermaid
flowchart LR

    P1["PHASE 1<br/><br/>Initial EV3 Prototype<br/><br/>Basic mobility<br/>Initial sensing<br/>Early autonomous control"]

    P2["PHASE 2<br/><br/>Mechanical + Navigation Development<br/><br/>Ackermann steering<br/>Motor A / Motor B roles<br/>Ultrasonic geometry<br/>S4 floor sensing"]

    P3["PHASE 3<br/><br/>Sensor + Vision + Control Experimentation<br/><br/>Sensor-placement tests<br/>Gyro experiments<br/>HuskyLens + Nano<br/>Pixy2.1 experiments<br/>Recovery + arbitration concepts"]

    P4["PHASE 4 — CURRENT<br/><br/>Competition Architecture<br/><br/>S1 round-specific<br/>S2 LEFT + S3 RIGHT<br/>S4 Color<br/>Gyro Open<br/>Pixy2.1 Obstacles<br/>State-based control"]

    P1 --> P2
    P2 --> P3
    P3 --> P4
```

The four phases represent major architectural stages rather than individual software revisions.

Small tuning changes such as:

```text
steering gain adjustments

color thresholds

parking distances

Pixy confirmation values

speed changes
```

remain part of the current phase unless they create a major architectural redesign.

---

# Evolution Overview

| Phase | Main Engineering Focus | Controller | Status |
|---|---|---|---|
| [Phase 1](Phase1.md) | Initial mobility and autonomous-control prototype | LEGO EV3 | Legacy |
| [Phase 2](Phase2.md) | Mechanical design, Ackermann steering, navigation and sensor geometry | LEGO EV3 | Legacy development |
| [Phase 3](Phase3.md) | Sensor, vision and control experimentation | LEGO EV3 | Legacy development |
| [Phase 4](Phase4.md) | Current competition architecture | LEGO EV3 | **CURRENT** |

The purpose of preserving all four phases is to show not only:

```text
what Piolín looks like now
```

but also:

```text
why Piolín looks and behaves this way now
```

---

# Phase 1 — Initial EV3 Prototype

### [View Phase 1 Documentation](Phase1.md)

Phase 1 represents the beginning of Piolín.

The objective was to create a functional EV3 vehicle that could:

```text
move autonomously

respond to basic sensor information

test steering behavior

run early Python control logic
```

At this stage, the robot was primarily a learning and experimentation platform.

The development questions were relatively fundamental:

```text
Can the vehicle move predictably?

How does it react to steering commands?

How can distance sensing affect movement?

What mechanical problems become visible during real driving?
```

The architecture was intentionally simple.

```text
EV3
 ↓
basic sensing
 ↓
basic control
 ↓
motors
 ↓
vehicle movement
```

Phase 1 revealed that successful Future Engineers navigation would require more than simply commanding motors.

The team needed to understand the relationship between:

```text
mechanical geometry

sensor placement

vehicle speed

steering response

physical trajectory
```

These observations defined the goals of Phase 2.

---

# Phase 2 — Mechanical and Navigation Development

### [View Phase 2 Documentation](Phase2.md)

Phase 2 focused on transforming Piolín from a basic mobile prototype into a more deliberate autonomous vehicle architecture.

One of the most important developments was the adoption and refinement of:

```text
ACKERMANN-STYLE FRONT STEERING
```

The motor responsibilities also became clearly separated:

```text
Motor A
→ rear propulsion
```

```text
Motor B
→ front steering
```

This created the vehicle structure that would continue into later versions.

Phase 2 also expanded ultrasonic navigation.

The engineering question changed from:

```text
Is something nearby?
```

toward:

```text
Where is Piolín relative to the surrounding course geometry?
```

This encouraged experiments with:

```text
left sensing

right sensing

different sensor positions

different sensor orientations
```

and eventually established the importance of lateral course measurements.

---

## Floor Landmark Development

Phase 2 also strengthened the role of the downward EV3 Color Sensor.

The course contains:

```text
BLUE

ORANGE
```

floor markings.

These became navigation landmarks rather than simply isolated color readings.

The initial direction concept developed toward:

```text
FIRST BLUE
→ COUNTERCLOCKWISE
```

```text
FIRST ORANGE
→ CLOCKWISE
```

This allowed the course itself to provide information about the required driving direction.

---

## Main Phase 2 Contribution

Phase 2 established that:

> **Mechanical design, sensor geometry, and navigation software must be developed together.**

The robot's physical steering geometry directly affects:

```text
turning radius

wall distance

corner behavior

sensor readings

control response
```

This systems-level relationship became one of the foundations of later Piolín development.

---

# Phase 3 — Sensor, Vision, and Control Experimentation

### [View Phase 3 Documentation](Phase3.md)

Phase 3 was the most experimental stage of Piolín's development.

By this point, Piolín had a stronger mechanical and navigation foundation.

The new challenge was the Obstacle Challenge.

Piolín now needed to answer:

```text
What object is ahead?

Is it Red?

Is it Green?

Which side must I pass?

When have I physically cleared it?

How should I return to the normal course?
```

Distance sensing alone could not answer these questions.

Vision became necessary.

---

## Vision Experiments

Phase 3 included multiple approaches to camera-based perception.

One important experimental architecture used:

```text
HuskyLens
      ↓
Arduino Nano
      ↓
EV3
```

This demonstrated that external vision could be integrated with Piolín.

However, it also introduced additional:

```text
hardware

communication

wiring

debugging

software integration
```

layers.

The architecture became valuable development evidence but was eventually moved to legacy status.

---

## Pixy2.1 Development

Phase 3 also introduced Pixy2.1 experimentation.

Pixy could provide:

```text
signature

x

y

width

height
```

for detected objects.

This led to a major architectural distinction:

```text
SIGNATURE
→ tells Piolín WHAT the target is
```

while:

```text
x / y / width / height
→ describe WHERE and HOW RELEVANT it is
```

This became particularly important for obstacle rules.

```text
RED
→ PASS RIGHT
```

```text
GREEN
→ PASS LEFT
```

The pillar's position inside the camera image does not redefine these rules.

---

## Moving Beyond Direct Camera Reactions

One of the strongest lessons from Phase 3 was:

```text
CAMERA DETECTION
≠
DIRECT MOTOR COMMAND
```

Early obstacle logic could behave approximately like:

```text
camera sees Red
→ steer
```

but real testing exposed problems such as:

```text
temporary detection loss

multiple visible blocks

wrong target selection

controller conflict

late avoidance

incorrect recovery
```

This motivated the more structured pipeline:

```text
DETECT
   ↓
VALIDATE
   ↓
SELECT
   ↓
CONFIRM
   ↓
LOCK
   ↓
MANEUVER
```

---

## Recovery and Pass Confirmation

Phase 3 also revealed that obstacle avoidance does not end when the camera loses the pillar.

```text
TARGET LOST
≠
TARGET PASSED
```

Piolín may lose visual contact because the vehicle and camera rotate during the maneuver.

The development therefore moved toward:

```text
AVOID
   ↓
PASS_CONFIRM
   ↓
RECOVER
   ↓
NORMAL
```

This became one of the major software concepts carried into Phase 4.

---

## Controller Conflict

Another important failure mode occurred when several behaviors attempted to control Motor B at the same time.

For example:

```text
pillar avoidance
→ RIGHT
```

while:

```text
wall correction
→ LEFT
```

This showed that Piolín required a control-authority hierarchy.

The concept developed toward:

```text
CRITICAL SAFETY
      ↓
ACTIVE MANEUVER
      ↓
NORMAL NAVIGATION
```

which became explicit in Phase 4.

---

# Phase 4 — Current Competition Architecture

### [View Phase 4 Documentation](Phase4.md)

Phase 4 represents the **current Piolín architecture**.

The purpose of Phase 4 is not to maximize the number of sensors or algorithms.

Instead, each subsystem is assigned a clearly defined responsibility.

<div align="center">

Piolín Phase 4 current Open Challenge configuration

<br>

<sub><b>Figure 1.</b> Piolín's current Phase 4 Open Challenge configuration.</sub>

</div>

The common architecture is:

```text
LEGO MINDSTORMS EV3
        │
        ├── Motor A → rear propulsion
        │
        ├── Motor B → Ackermann steering
        │
        ├── S2 → LEFT Ultrasonic
        │
        ├── S3 → RIGHT Ultrasonic
        │
        └── S4 → Color Sensor
```

S1 changes according to the competition round.

---

# Current Open Challenge Architecture

```text
S1
→ EV3 Gyro Sensor

S2
→ LEFT Ultrasonic

S3
→ RIGHT Ultrasonic

S4
→ Color Sensor
```

<div align="center">

Piolín Phase 4 Open Challenge wiring

<br>

<sub><b>Figure 2.</b> Phase 4 Open Challenge wiring and sensor configuration.</sub>

</div>

The Open architecture separates:

```text
S2/S3
→ lateral geometry
```

```text
Gyro
→ heading / vehicle rotation
```

```text
S4
→ course landmarks
```

This gives the navigation system different information about:

```text
WHERE THE VEHICLE IS

WHERE THE VEHICLE IS POINTING

WHERE IT IS IN THE COURSE SEQUENCE
```

---

# Current Obstacle Challenge Architecture

During Obstacles:

```text
S1
→ Pixy2.1

S2
→ LEFT Ultrasonic

S3
→ RIGHT Ultrasonic

S4
→ Color Sensor
```

There is no gyro installed in this configuration.

<div align="center">

Piolín Phase 4 current Obstacle Challenge configuration

<br>

<sub><b>Figure 3.</b> Piolín's Phase 4 Obstacle Challenge configuration with Pixy2.1.</sub>

</div>

The corresponding wiring architecture is:

<div align="center">

Piolín Phase 4 Obstacle Challenge wiring

<br>

<sub><b>Figure 4.</b> Phase 4 Obstacle Challenge wiring and sensor configuration.</sub>

</div>

The design decision is:

```text
OPEN
needs strong heading information
→ GYRO
```

while:

```text
OBSTACLES
needs visual object identity
→ PIXY2.1
```

The two devices therefore share S1 as **round-specific alternatives**.

They are not installed simultaneously in the current architecture.

---

# Phase 4 Vision Architecture

Pixy2.1 is directly integrated with the EV3 through S1 during the Obstacle Challenge.

The current signature convention is:

```text
sig1
→ PINK
→ Parking
```

```text
sig2
→ RED
→ PASS RIGHT
```

```text
sig3
→ GREEN
→ PASS LEFT
```

The processing objective is:

```text
PIXY
   ↓
VALIDATION
   ↓
TARGET SELECTION
   ↓
CONFIRMATION
   ↓
TARGET LOCK
   ↓
STATE MACHINE
   ↓
CONTROLLER
```

rather than:

```text
PIXY
→ MOTOR B
```

This separation is one of the most significant architectural improvements produced by Piolín's evolution.

---

# Phase 4 Software Architecture

The current software direction is increasingly state-oriented.

Important behavioral states include:

```text
START / ACQUIRE

NORMAL

TARGET_ACQUIRE

AVOID

PASS_CONFIRM

RECOVER

CORNER

PARKING

STOP
```

Each state represents a different physical objective.

For example:

```text
NORMAL
→ maintain course geometry
```

```text
AVOID
→ execute required pillar trajectory
```

```text
PASS_CONFIRM
→ determine whether the pillar has actually been cleared
```

```text
RECOVER
→ return toward a usable course position
```

```text
PARKING
→ construct final parking pose
```

This structure prevents every navigation behavior from operating simultaneously with equal authority.

---

# Control Arbitration

Piolín has multiple possible controllers but only one physical steering actuator:

```text
Motor B
```

Phase 4 therefore introduces explicit controller arbitration.

```text
CRITICAL SAFETY
      ↓
ACTIVE MANEUVER
      ↓
NORMAL NAVIGATION
```

The software decides which controller currently owns the trajectory before sending the final command to Motor B.

This avoids uncontrolled combinations such as:

```text
wall correction
+
pillar correction
+
corner correction
+
recovery correction
```

which can otherwise create unstable or contradictory steering.

---

# Color Event Processing

The S4 Color Sensor also became more structured through the evolution.

Instead of counting every individual sensor reading:

```text
BLUE
BLUE
BLUE
BLUE
```

as multiple events, the current concept is:

```text
CLASSIFY
   ↓
CONFIRM
   ↓
LATCH
   ↓
COUNT ONCE
   ↓
WAIT FOR NEUTRAL
   ↓
RELEASE
   ↓
RE-ARM
```

The objective is:

```text
ONE PHYSICAL COURSE MARKING
→ ONE SOFTWARE EVENT
```

This supports:

```text
direction determination

course progression

corner context

parking eligibility
```

---

# 3D-Printed Sensor Integration

Phase 4 also includes custom 3D-printed sensor components.

Current models include:

```text
ColorSensorCasing.stl

PIXY_Case1.stl

PIXY_Case2.stl
```

The Color Sensor casing helps create a more controlled optical environment around S4.

The Pixy casing supports a more repeatable physical installation of the camera.

These parts demonstrate the relationship between:

```text
MECHANICAL DESIGN
      ↓
SENSOR INSTALLATION
      ↓
PERCEPTION
      ↓
SOFTWARE CALIBRATION
```

The manufacturing process is documented under:

[3D Printing Documentation](../3dprint/PrintingProcess.md)

---

# Architecture Evolution Matrix

| Engineering Area | Phase 1 | Phase 2 | Phase 3 | Phase 4 — Current |
|---|---|---|---|---|
| **Main controller** | EV3 | EV3 | EV3 | **EV3** |
| **Primary objective** | Basic prototype | Mechanical/navigation development | Sensor/vision experimentation | **Competition architecture** |
| **Propulsion** | Early EV3 implementation | Motor A role established | Refined | **Motor A rear propulsion** |
| **Steering** | Early mechanism | Ackermann development | Refinement | **Motor B Ackermann steering** |
| **Ultrasonic sensing** | Simple sensing | Placement experiments | Multiple configurations evaluated | **S2 LEFT + S3 RIGHT** |
| **Floor sensing** | Early | S4 integration | Event-processing development | **S4 event system** |
| **Open orientation** | Not mature | Experimental | Gyro evaluated | **S1 Gyro** |
| **Obstacle vision** | None | Not mature | HuskyLens/Nano/Pixy experiments | **S1 Pixy2.1** |
| **Camera architecture** | None | None | Multiple experimental paths | **Direct Pixy2.1 → EV3 S1** |
| **Obstacle decision** | None | Early | Reactive experimentation | **Structured perception + state logic** |
| **Target handling** | None | None | Confirmation/lock concepts | **Validate → select → confirm → lock** |
| **Pass verification** | None | None | Need identified | **PASS_CONFIRM architecture** |
| **Recovery** | None | Early | Need identified | **Dedicated RECOVER state** |
| **Controller priority** | Basic | Basic | Conflict discovered | **Explicit arbitration** |
| **Color counting** | Basic | Course landmarks | Event concepts | **Confirmed discrete events** |
| **Parking** | Not developed | Early concept | Experimental | **Dedicated subsystem under calibration** |

---

# What Remained Constant

The most important continuity throughout Piolín's evolution is the EV3 platform.

```text
PHASE 1 → EV3
PHASE 2 → EV3
PHASE 3 → EV3
PHASE 4 → EV3
```

The project did not achieve greater capability simply by replacing the central computer.

Instead, improvement came from progressively refining:

```text
MECHANICS

STEERING

SENSOR PLACEMENT

PERCEPTION

CONTROL

SOFTWARE ORGANIZATION

TESTING
```

This continuity makes it possible to trace current design decisions back to earlier experiments.

---

# What Changed the Most

Although the controller remained constant, almost everything around it became more structured.

The evolution of Piolín can be represented as:

```text
BASIC MOBILITY
      ↓
VEHICLE GEOMETRY
      ↓
COURSE GEOMETRY
      ↓
MULTI-SENSOR NAVIGATION
      ↓
VISUAL PERCEPTION
      ↓
TARGET VALIDATION
      ↓
STATE-BASED BEHAVIOR
      ↓
CONTROL ARBITRATION
      ↓
RECOVERY
      ↓
EVENT PROCESSING
      ↓
PARKING
```

The largest improvement was therefore not one individual component.

It was the increasing organization of the robot as a complete system.

---

# From More Hardware to Clearer Responsibilities

An important lesson from Phase 3 was that:

```text
MORE SENSORS
```

does not automatically mean:

```text
BETTER ROBOT
```

Every sensor must answer a useful question.

The current architecture follows this principle.

### S2 and S3

```text
What is Piolín's lateral relationship with the course?
```

### S4

```text
What floor landmark is Piolín crossing?
```

### Gyro during Open

```text
How is the vehicle oriented / rotating?
```

### Pixy2.1 during Obstacles

```text
What visual target is ahead?
```

### State machine

```text
What objective should Piolín currently execute?
```

### Arbitration

```text
Which controller is allowed to command Motor B?
```

This clarity is one of the defining characteristics of Phase 4.

---

# Current vs. Legacy

The evolution documentation deliberately preserves obsolete approaches.

```text
PHASE 1
PHASE 2
PHASE 3
→ DEVELOPMENT HISTORY / LEGACY
```

```text
PHASE 4
→ CURRENT ARCHITECTURE
```

Legacy material may include systems that were useful during experimentation but are no longer active, such as:

```text
HuskyLens

Arduino Nano vision bridge

temporary ultrasonic arrangements

earlier camera configurations

earlier navigation logic
```

These are retained because they provide evidence of:

```text
experimentation

failure analysis

design trade-offs

engineering decisions
```

They should not be interpreted as current hardware.

---

# Evolution of the Engineering Questions

The questions PiolínTech asked also became more sophisticated.

### Phase 1

```text
Can we make the robot move autonomously?
```

### Phase 2

```text
Can we make the vehicle follow a repeatable course geometry?
```

### Phase 3

```text
Can the robot understand obstacles and coordinate multiple sensors?
```

### Phase 4

```text
Can each subsystem have a clear role,
and can Piolín reliably decide which behavior
should control the vehicle at each moment?
```

This progression reflects the transition from:

```text
PROTOTYPING
```

to:

```text
SYSTEMS ENGINEERING
```

---

# Engineering Process Behind the Evolution

Each phase follows the same broader development cycle:

```text
OBSERVE
   ↓
IDENTIFY FAILURE
   ↓
FIND FIRST INCORRECT LAYER
   ↓
FORM HYPOTHESIS
   ↓
CHANGE ONE PRIMARY VARIABLE
   ↓
TEST
   ↓
COMPARE
   ↓
KEEP OR REVERT
   ↓
DOCUMENT
```

Failures therefore became part of the design process.

A prototype that was replaced still contributed information.

For example:

```text
HuskyLens + Nano
→ demonstrated external vision integration
→ revealed additional integration complexity
→ informed direct Pixy2.1 architecture
```

Likewise:

```text
multiple ultrasonic configurations
→ demonstrated different geometric information
→ helped identify the value of permanent lateral sensing
```

This is why earlier phases remain documented.

---

# Evolution Summary

The complete development path can be summarized as:

```text
                        PHASE 1
                 INITIAL EV3 PROTOTYPE
                          │
                          ▼
                  BASIC AUTONOMY WORKS
                          │
                          ▼
                        PHASE 2
             MECHANICAL + NAVIGATION DEVELOPMENT
                          │
             ┌────────────┼────────────┐
             ▼            ▼            ▼
         ACKERMANN      MOTOR A/B   COURSE SENSING
             │            │            │
             └────────────┼────────────┘
                          ▼
                        PHASE 3
             SENSOR + VISION EXPERIMENTATION
                          │
            ┌─────────────┼─────────────┐
            ▼             ▼             ▼
      SENSOR TESTS    CAMERA TESTS   CONTROL TESTS
            │             │             │
            └─────────────┼─────────────┘
                          ▼
                ENGINEERING LESSONS
                          │
                          ▼
                        PHASE 4
               CURRENT ARCHITECTURE
                          │
      ┌───────────────────┼───────────────────┐
      ▼                   ▼                   ▼
   OPEN                 COMMON             OBSTACLES
      │                   │                   │
 S1 GYRO             S2 LEFT US          S1 PIXY2.1
                     S3 RIGHT US
                     S4 COLOR
      │                   │                   │
      └───────────────────┼───────────────────┘
                          ▼
                     PERCEPTION
                          ↓
                    STATE MACHINE
                          ↓
                      CONTROL
                          ↓
                    ARBITRATION
                          ↓
                MOTOR A + MOTOR B
                          ↓
                   PIOLÍN MOVEMENT
```

---

# Current Development Status

Phase 4 is the current architecture, but this does not mean every calibration parameter is permanently finished.

The current Open system continues to refine areas such as:

```text
corner consistency

initial acquisition

course-event reliability

parking behavior
```

The current Obstacle architecture continues development in:

```text
target relevance

multi-block selection

pillar avoidance

pass confirmation

recovery

controller arbitration

parking
```

These are treated as **Phase 4 development and calibration**, not as additional robot generations.

A future Phase 5 should only be created if Piolín undergoes a significant architectural change.

---

# Recommended Reading Order

For a complete understanding of Piolín's evolution:

1. [Phase 1 — Initial EV3 Prototype](Phase1.md)
2. [Phase 2 — Mechanical and Navigation Development](Phase2.md)
3. [Phase 3 — Sensor, Vision, and Control Experimentation](Phase3.md)
4. [Phase 4 — Current Competition Architecture](Phase4.md)

The sequence should be read as:

```text
WHAT WE BUILT
      ↓
WHAT WE OBSERVED
      ↓
WHAT FAILED
      ↓
WHAT WE CHANGED
      ↓
WHY THE CURRENT DESIGN EXISTS
```

---

# Final Evolution Principle

Piolín's development demonstrates that engineering progress does not necessarily require replacing the entire platform.

The EV3 remained at the center of every generation.

What changed was the team's understanding of how the surrounding systems should interact.

```text
PHASE 1
Learn to control the vehicle
        ↓
PHASE 2
Understand mechanics and navigation
        ↓
PHASE 3
Understand sensors, vision and controller interaction
        ↓
PHASE 4
Assign clear responsibilities and integrate the complete system
```

The central principle of Piolín's evolution is:

> **Each phase of Piolín was built from the lessons of the previous one. The current robot is not the result of replacing the original concept, but of progressively refining its mechanics, sensing, perception, control, and software architecture until each subsystem had a clear purpose within the complete autonomous vehicle.**

---

<div align="center">

### [Phase 1](Phase1.md) · [Phase 2](Phase2.md) · [Phase 3](Phase3.md) · [Phase 4 — Current](Phase4.md)

<br>

### [← Back to PiolínTech Main README](../../README.md)

</div>

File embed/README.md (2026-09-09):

# PiolínTech Embedded Engineering Diagrams

The `embed/` directory contains the main **engineering diagrams, flowcharts, and visual architecture references** used throughout the PiolínTech WRO Future Engineers 2026 repository.

These files complement the detailed documentation under `docs/` by providing fast visual explanations of Piolín's:

```text
navigation architecture

Pixy2.1 vision processing

controller arbitration

obstacle strategy

floor-event processing

parking

calibration process

engineering workflow

complete system architecture
```

Most current diagrams are stored as Markdown files containing **Mermaid flowcharts** so they can be rendered directly by GitHub while remaining easy to edit and version-control.

The directory also contains a small number of PNG diagrams used as static engineering evidence or legacy documentation.

---

# 1. Directory Structure

```text
embed/
│
├── 01_NVStateFC.md
├── 02_VProcessing.md
├── 03_TorqueCalc.png
├── 04_ControlArbitration.md
├── 05_ObstacleStrategyFC.md
├── 06_ColorEventFC.md
├── 07_ParkingStateFC.md
├── 08_ParkingCalibrationFC.md
├── 09_EngineeringProcessFC.md
├── 10_SystemArchitectureFC.md
│
├── legacy_layered_testing.png
├── legacy_testing_cycle.png
│
└── README.md
```

The numbered files represent the current visual documentation set.

Files beginning with:

```text
legacy_
```

represent earlier development material and should not be interpreted as the current system architecture.

---

# 2. Visual Documentation Map

The diagrams can be understood as different levels of Piolín's system.

```text
                     10 SYSTEM ARCHITECTURE
                              │
                 ┌────────────┼────────────┐
                 │            │            │
                 ▼            ▼            ▼
           01 NAVIGATION   02 VISION   06 COLOR EVENTS
              STATES       PROCESSING
                 │            │
                 ├────────────┘
                 │
                 ▼
          04 CONTROL ARBITRATION
                 │
        ┌────────┼───────────┐
        │        │           │
        ▼        ▼           ▼
    05 PILLAR  07 PARKING  OTHER STATES
    STRATEGY      │
                  ▼
           08 PARKING CALIBRATION

         09 ENGINEERING PROCESS
                  │
                  ▼
          HOW THE SYSTEM EVOLVES
```

The files therefore do not duplicate each other.

Each one represents a different engineering layer.

---

# 3. Current Flowcharts

## 01 — Navigation State Flowchart

### [01_NVStateFC.md](01_NVStateFC.md)

This is the high-level **Obstacle Challenge navigation state machine**.

It shows how Piolín moves between:

```text
START

ACQUIRE

NORMAL

TARGET_ACQUIRE

AVOID

PASS_CONFIRM

RECOVER

CORNER

PARKING

STOP
```

Its main purpose is to answer:

> **What is Piolín currently trying to accomplish?**

This diagram should be used as the primary visual reference for the navigation-state architecture.

---

## 02 — Pixy2.1 Vision Processing

### [02_VProcessing.md](02_VProcessing.md)

This diagram shows how raw Pixy2.1 blocks become useful perception information.

The pipeline is:

```text
PIXY BLOCKS
      ↓
VALIDATE
      ↓
CLASSIFY
      ↓
BUILD CANDIDATES
      ↓
RANK RELEVANCE
      ↓
CONFIRM
      ↓
LOCK
      ↓
OUTPUT TARGET
```

It reinforces the architectural separation:

```text
Pixy2.1
→ perception
```

rather than:

```text
Pixy2.1
→ direct Motor B command
```

The current signature mapping is:

```text
sig1
→ Pink
→ Parking
```

```text
sig2
→ Red
→ PASS RIGHT
```

```text
sig3
→ Green
→ PASS LEFT
```

---

# 4. Torque Calculation Graphic

## 03 — Torque Calculation

`03_TorqueCalc.png`

This is a static engineering graphic related to torque calculations.

Unlike the Mermaid flowcharts, this file is a normal image and can be embedded directly in Markdown using:

```html
<img
  src="../embed/03_TorqueCalc.png"
  alt="Torque calculation diagram"
/>
```

The exact relative path depends on the location of the Markdown document using the image.

This file is separate from Piolín's navigation architecture and belongs to the repository's supporting engineering-analysis material.

---

# 5. Control Architecture

## 04 — Control Arbitration

### [04_ControlArbitration.md](04_ControlArbitration.md)

This flowchart explains how Piolín selects **one final steering command** when several subsystems could request different actions.

The central priority is:

```text
CRITICAL SAFETY
      ↓
ACTIVE MANEUVER
      ↓
NORMAL NAVIGATION
```

This prevents uncontrolled combinations such as:

```text
wall correction
+
pillar correction
+
corner correction
+
recovery correction
```

from fighting each other.

It explains why:

```text
NORMAL
→ wall geometry authority
```

```text
AVOID
→ pillar trajectory authority
```

```text
CORNER
→ corner authority
```

```text
RECOVER
→ recovery authority
```

```text
PARKING
→ parking authority
```

while critical physical wall protection remains independent.

---

# 6. Obstacle Maneuver

## 05 — Obstacle Strategy Flowchart

### [05_ObstacleStrategyFC.md](05_ObstacleStrategyFC.md)

This diagram is a detailed view of **one complete pillar maneuver**.

The sequence is:

```text
NORMAL
   ↓
DETECT
   ↓
VALIDATE
   ↓
SELECT
   ↓
CONFIRM
   ↓
LOCK
   ↓
APPROACH
   ↓
AVOID
   ↓
PASS_CONFIRM
   ↓
RELEASE
   ↓
RECOVER
   ↓
NORMAL
```

It also shows the fixed WRO passing rules:

```text
RED
→ PASS RIGHT
```

```text
GREEN
→ PASS LEFT
```

This diagram is more detailed than `01_NVStateFC.md`.

`01_NVStateFC.md` explains:

```text
the complete navigation state system
```

while `05_ObstacleStrategyFC.md` explains:

```text
what happens inside one pillar-handling sequence
```

---

# 7. Floor Event Processing

## 06 — Color Event Flowchart

### [06_ColorEventFC.md](06_ColorEventFC.md)

This diagram explains how the downward S4 Color Sensor converts continuous floor observations into discrete navigation events.

The processing sequence is:

```text
READ FLOOR
      ↓
CLASSIFY
      ↓
CANDIDATE
      ↓
CONFIRM
      ↓
CHECK SEPARATION
      ↓
ACCEPT EVENT
      ↓
COUNT
      ↓
LATCH
      ↓
WAIT FOR NEUTRAL
      ↓
RELEASE
      ↓
RE-ARM
```

The primary objective is:

```text
one physical marking
→ one software event
```

rather than:

```text
one physical marking
→ many control-loop counts
```

The first confirmed event also supports course-direction initialization:

```text
BLUE first
→ COUNTERCLOCKWISE
```

```text
ORANGE first
→ CLOCKWISE
```

Later accepted events provide course-progress information.

---

# 8. Parking

## 07 — Parking State Flowchart

### [07_ParkingStateFC.md](07_ParkingStateFC.md)

This diagram represents the complete terminal parking-state sequence.

```text
COURSE COMPLETE
      ↓
PARKING ELIGIBLE
      ↓
PINK CONFIRMED
      ↓
TARGET LOCK
      ↓
APPROACH
      ↓
ENTRY
      ↓
ALIGN
      ↓
FINAL
      ↓
STOP
```

Parking is therefore not modeled as:

```text
Pink visible
→ turn
→ stop
```

Instead, course state, Pixy perception, physical geometry, encoder progression, and steering state contribute to the final maneuver.

`STOP` is terminal.

Once Piolín reaches it, normal autonomous navigation does not resume.

---

## 08 — Parking Calibration Flowchart

### [08_ParkingCalibrationFC.md](08_ParkingCalibrationFC.md)

This diagram explains **how the parking parameters are calibrated**, rather than how parking itself operates.

The engineering process is:

```text
FREEZE HARDWARE
      ↓
VERIFY SENSORS
      ↓
VERIFY STEERING
      ↓
CALIBRATE PIXY
      ↓
CALIBRATE APPROACH
      ↓
FREEZE APPROACH
      ↓
CALIBRATE ENTRY
      ↓
FREEZE ENTRY
      ↓
CALIBRATE ALIGNMENT
      ↓
FREEZE ALIGNMENT
      ↓
CALIBRATE FINAL POSITION
      ↓
CALIBRATE STOP
      ↓
REPEAT
      ↓
SAVE BASELINE
```

The key principle is:

> **A later parking phase should not be used to compensate for an earlier phase that is already incorrect.**

For example:

```text
FINAL
```

should not compensate for poor:

```text
ALIGNMENT
```

and alignment should not compensate for a poor:

```text
ENTRY
```

---

# 9. Engineering Development

## 09 — Engineering Process Flowchart

### [09_EngineeringProcessFC.md](09_EngineeringProcessFC.md)

This diagram represents the development methodology used by PiolínTech.

The cycle is:

```text
REQUIREMENT
      ↓
OBSERVE
      ↓
FIND FIRST INCORRECT LAYER
      ↓
FORM HYPOTHESIS
      ↓
PRESERVE BASELINE
      ↓
CHANGE ONE PRIMARY VARIABLE
      ↓
CONTROLLED TEST
      ↓
COLLECT EVIDENCE
      ↓
REPEAT
      ↓
KEEP OR REVERT
      ↓
REGRESSION TEST
      ↓
DOCUMENT
      ↓
INTEGRATE
```

The diagnostic layers include:

```text
MECHANICS

SENSORS

PERCEPTION

STATE / DECISION

CONTROL

ARBITRATION

ACTUATION
```

The main engineering rule is to correct the **first layer that becomes incorrect**, rather than immediately changing the subsystem associated with the final visible symptom.

---

# 10. Complete System Architecture

## 10 — System Architecture Flowchart

### [10_SystemArchitectureFC.md](10_SystemArchitectureFC.md)

This is the highest-level technical diagram in the `embed/` directory.

It connects:

```text
PHYSICAL COURSE
      ↓
SENSORS
      ↓
ACQUISITION
      ↓
VALIDATION
      ↓
PERCEPTION
      ↓
STATE MACHINE
      ↓
CONTROLLERS
      ↓
CONTROL ARBITRATION
      ↓
MOTORS
      ↓
PHYSICAL MOTION
      ↓
SENSOR FEEDBACK
```

It also documents the two round-specific S1 configurations.

### Open

```text
S1 → Gyro
S2 → LEFT Ultrasonic
S3 → RIGHT Ultrasonic
S4 → Color Sensor
```

### Obstacles

```text
S1 → Pixy2.1
S2 → LEFT Ultrasonic
S3 → RIGHT Ultrasonic
S4 → Color Sensor
```

The system architecture diagram should be used when a reader needs to understand **how all Piolín subsystems connect together**.

---

# 11. Relationship Between the Current Diagrams

The current visual set can be read from highest level to lowest level.

### Complete system

```text
10_SystemArchitectureFC.md
```

answers:

> How does the entire robot work as one closed-loop system?

### Navigation behavior

```text
01_NVStateFC.md
```

answers:

> Which autonomous state is active?

### Perception

```text
02_VProcessing.md
```

answers:

> How does Pixy information become a target?

```text
06_ColorEventFC.md
```

answers:

> How does a floor reading become a course event?

### Controller selection

```text
04_ControlArbitration.md
```

answers:

> Which controller is allowed to command steering?

### Specific maneuver

```text
05_ObstacleStrategyFC.md
```

answers:

> How does Piolín completely handle one pillar?

### Terminal maneuver

```text
07_ParkingStateFC.md
```

answers:

> How does Piolín execute parking?

```text
08_ParkingCalibrationFC.md
```

answers:

> How is that parking behavior calibrated?

### Development method

```text
09_EngineeringProcessFC.md
```

answers:

> How does PiolínTech improve the robot when something fails?

---

# 12. Current vs. Legacy Diagrams

The repository also contains:

```text
legacy_layered_testing.png

legacy_testing_cycle.png
```

These files represent earlier engineering-development material.

They are intentionally preserved because they provide evidence of:

```text
earlier testing methodology

architecture evolution

engineering iteration
```

However, they should not override the current architecture documented by the numbered flowcharts.

The distinction is:

```text
01–10
→ CURRENT VISUAL DOCUMENTATION
```

```text
legacy_*
→ HISTORICAL / DEVELOPMENT EVIDENCE
```

This follows the same current-vs-legacy philosophy used throughout the PiolínTech repository.

---

# 13. How to Use the Mermaid Files

Files such as:

```text
01_NVStateFC.md

02_VProcessing.md

04_ControlArbitration.md
```

contain Mermaid blocks.

For example:

````text
```mermaid
flowchart TD

    A[Sensor]
    B[Processing]
    C[Decision]

    A --> B
    B --> C
```

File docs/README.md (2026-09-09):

# PiolínTech WRO 2026 — Technical Documentation

<div align="center">

Piolín in Open Challenge configuration

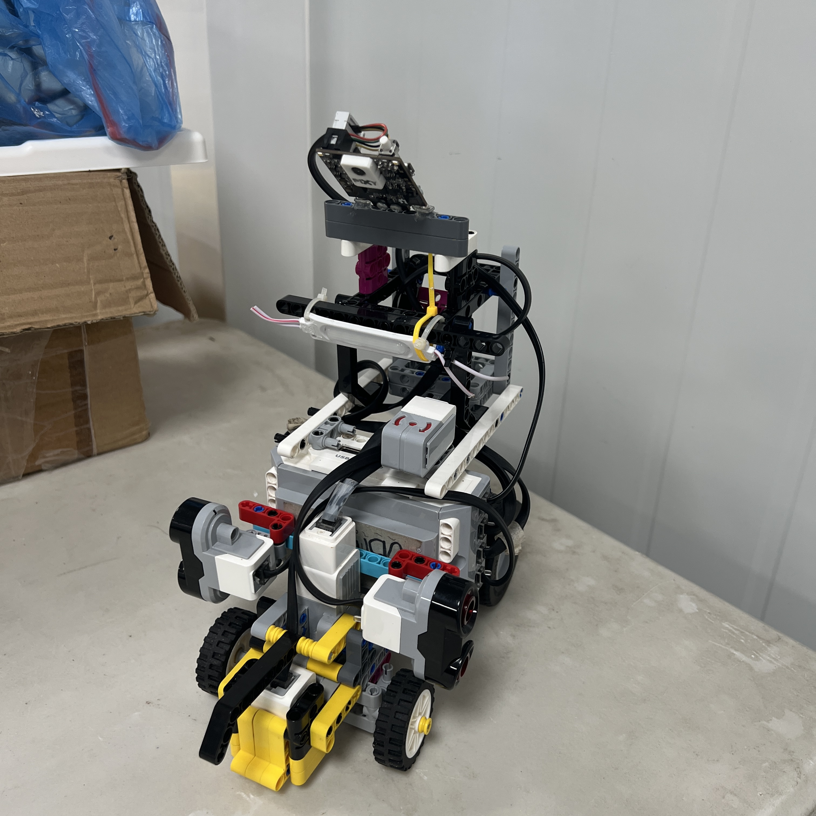
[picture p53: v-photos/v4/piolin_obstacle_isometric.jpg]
Piolín in Obstacle Challenge configuration


<br>

<sub><b>Figure D.1.</b> Piolín uses the same mechanical vehicle for both WRO Future Engineers rounds while changing the S1 sensing configuration according to the task.</sub>

</div>

This directory contains the engineering documentation for **Piolín**, PiolínTech's WRO Future Engineers 2026 autonomous vehicle.

The documentation is intended to explain more than the final robot.

It records:

```text
what Piolín is

how it was designed

how each subsystem works

why important decisions were made

which alternatives were tested

what did not work

how the software is organized

how the robot is calibrated

how results are tested

how another team could reproduce the system
```

The project is documented as an integrated engineering system rather than as separate pieces of hardware and code.

The main documentation areas are:

```text
PROJECT OVERVIEW

MOBILITY & MECHANICAL DESIGN

COMPONENTS

POWER & SENSORS

SOFTWARE & OBSTACLE STRATEGY

PARKING

SYSTEMS ENGINEERING

REPRODUCIBILITY
```

---

# 1. Piolín at a Glance

Piolín is a LEGO Mindstorms EV3-based autonomous vehicle designed for the **WRO Future Engineers 2026** competition.

Its current core architecture is:

```text
Controller
→ LEGO Mindstorms EV3 Brick

Motor A
→ EV3 Large Motor
→ rear propulsion

Motor B
→ EV3 Medium Motor
→ front Ackermann-style steering

S2
→ LEFT EV3 Ultrasonic Sensor

S3
→ RIGHT EV3 Ultrasonic Sensor

S4
→ downward-facing EV3 Color Sensor
```

Sensor Port S1 changes according to the competition round.

### Open Challenge

```text
S1 → EV3 Gyro Sensor
```

### Obstacle Challenge

```text
S1 → Pixy2.1
```

The Gyro Sensor and Pixy2.1 are **not installed simultaneously** in the current architecture.

All current competition hardware is LEGO Mindstorms EV3 except Pixy2.1.

The active power source is the:

```text
LEGO Mindstorms EV3 Rechargeable DC Battery
Model 45501
```

---

# 2. Current Hardware Architecture

<div align="center">

Piolín Open Challenge wiring

Piolín Obstacle Challenge wiring

<br>

<sub><b>Figure D.2.</b> Open and Obstacles preserve the same propulsion, steering, lateral ultrasonic, and floor-sensing architecture while changing S1.</sub>

</div>

| Port | Open Challenge | Obstacle Challenge |
| :---: | :--- | :--- |
| Motor A | Rear propulsion | Rear propulsion |
| Motor B | Ackermann steering | Ackermann steering |
| S1 | Gyro Sensor | Pixy2.1 |
| S2 | LEFT Ultrasonic | LEFT Ultrasonic |
| S3 | RIGHT Ultrasonic | RIGHT Ultrasonic |
| S4 | Color Sensor | Color Sensor |

One of the most important conventions throughout the repository is:

```text
S2 = LEFT

S3 = RIGHT
```

These are permanent **physical identities**.

Logical roles such as:

```text
inner

outer
```

may change with course direction, but the physical sensor names do not.

---

# 3. Documentation Structure

The documentation is divided by engineering responsibility.

```text
docs/
│
├── project_overview/
│
├── mobility_mechanical/
│
├── components/
│
├── power_sensors/
│
├── software_obstacles_strategy/
│   └── parking/
│
├── systems_engineering/
│
└── reproducibility/
```

Each section answers a different engineering question.

```text
PROJECT OVERVIEW
→ What is Piolín?

MOBILITY
→ How does Piolín physically move?

COMPONENTS
→ What hardware is installed?

POWER & SENSORS
→ How is information and power provided?

SOFTWARE
→ How does Piolín interpret the course and control motion?

SYSTEMS ENGINEERING
→ Why was the architecture chosen?

REPRODUCIBILITY
→ How can the system be reconstructed, calibrated, and tested?
```

---

# 4. Project Overview

Start here for the highest-level explanation of the project.

### [Project Overview](project_overview/01_ProjectOverview.md)

This document introduces:

```text
PiolínTech

WRO Future Engineers 2026

Piolín's engineering objective

Open Challenge architecture

Obstacle Challenge architecture

major subsystem relationships

development philosophy
```

It provides context before the reader moves into detailed mechanical, electrical, and software documentation.

---

# 5. Mobility and Mechanical Design

Piolín uses a car-like mechanical architecture based on:

```text
rear propulsion

front Ackermann-style steering
```

rather than differential drive.

<div align="center">

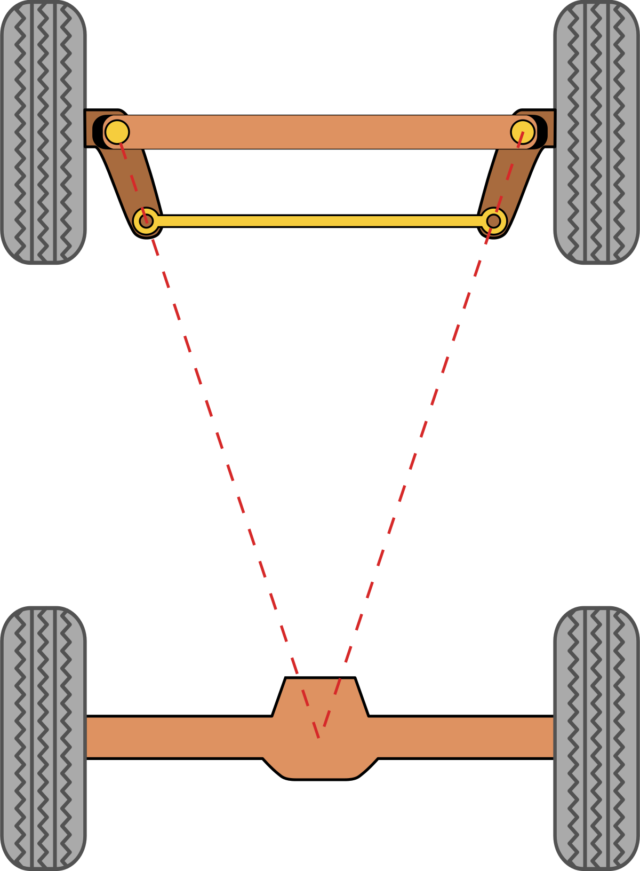
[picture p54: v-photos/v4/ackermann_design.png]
Piolín Ackermann steering design


<br>

<sub><b>Figure D.3.</b> Piolín's steering geometry determines the curved trajectories used for corners, obstacle avoidance, recovery, and parking.</sub>

</div>

The main mobility documents are:

### [Robot Mobility](mobility_mechanical/03_RMobility.md)

Explains the complete vehicle-motion architecture and how propulsion and steering work together.

### [Steering System](mobility_mechanical/04_steering.md)

Covers:

```text
Motor B

Ackermann linkage

steering geometry

left/right movement

mechanical limitations

software implications
```

### [Drivetrain](mobility_mechanical/05_drivetrain.md)

Documents:

```text
Motor A

rear propulsion

wheel transmission

vehicle movement

relationship between speed and steering
```

### [Mechanical Testing](mobility_mechanical/06_testing.md)

Describes the process used to evaluate:

```text
steering response

mechanical consistency

trajectory repeatability

physical integration
```

A central mechanical constraint is:

> **Piolín cannot rotate in place or translate directly sideways.**

Corners, obstacle maneuvers, recovery, and parking therefore require actual Ackermann arcs.

---

# 6. Components

The `components/` section documents the main physical elements of the current robot.

### [Hardware Overview](components/01_Hardwareoverview.md)

High-level inventory and subsystem relationships.

### [EV3 Brick](components/02_EV3.md)

Explains the role of the EV3 as:

```text
main controller

sensor interface

motor controller

software platform

power-distribution center
```

### [Motors](components/03_Motors.md)

Overview of both active motors.

### [Steering Motor](components/04_SteeringMotor.md)

Detailed documentation of Motor B and its steering responsibility.

### [Ultrasonic Sensors](components/05_UltrasonicSensors.md)

Documents the permanent:

```text
S2 LEFT

S3 RIGHT
```

lateral sensing architecture.

### [Color Sensor](components/06_ColorSensor.md)

Explains S4 floor sensing and the Color Sensor casing.

### [Pixy2.1 Vision](components/07_PixyVision.md)

Documents Pixy2.1 as the current non-LEGO vision component used in Obstacles.

### [Battery](components/08_Battery.md)

Documents the EV3 Rechargeable DC Battery 45501.

### [Power Distribution](components/09_PowerDistribution.md)

Explains how the EV3 supplies the active robot architecture.

### [Other Components](components/10_OtherComponents.md)

Covers supporting mechanical and electrical elements that do not require their own primary subsystem.

---

# 7. Power and Sensors

The `power_sensors/` section focuses on **sensor installation, sensing roles, and calibration** rather than general component descriptions.

### [Power and Sensor Configuration](power_sensors/01_PowerSensorconfig.md)

Defines both round-specific sensor architectures and the relationship between power, sensors, and the EV3.

### [Ultrasonic Sensor Design](power_sensors/02_USSensorD.md)

Explains:

```text
lateral mounting

S2/S3 roles

distance interpretation

geometry

limitations
```

### [Color Sensor](power_sensors/03_color_sensor.md)

Covers:

```text
downward floor detection

Blue and Orange markings

optical casing

course-state information
```

### [Pixy2.1 Camera](power_sensors/04_pixycam.md)

Documents the current Obstacle Challenge vision hardware, including:

```text
S1 integration

Pixy signatures

physical installation

3D-printed casing

camera limitations
```

### [Sensor Calibration](power_sensors/05_Calibration.md)

Explains why calibration is required and how sensing values should be obtained from the actual installed robot instead of assumed from theoretical values.

---

# 8. Software Architecture

The main software documentation is under:

```text
software_obstacles_strategy/
```

Although much of this section focuses on the more complex Obstacle Challenge, several architectural principles also originate from Open Challenge prototypes.

The overall philosophy is:

```text
SENSORS
   ↓
VALIDATION
   ↓
PERCEPTION
   ↓
STATE
   ↓
CONTROLLERS
   ↓
ARBITRATION
   ↓
ACTUATION
```

rather than:

```text
sensor sees something
→ immediately move motor
```

---

## 8.1 Software Architecture

### [Software Architecture](software_obstacles_strategy/01_SWArchitecture.md)

Explains the complete layered structure:

```text
sensor acquisition

filtering

geometry

perception

state management

controller authority

Motor A / Motor B output
```

It also documents control patterns already demonstrated in Piolín's Python prototypes, including:

```text
clamp()

short ultrasonic filtering

geometric fusion

steering smoothing

wall safety

debug telemetry
```

---

## 8.2 State Machine

### [State Machine](software_obstacles_strategy/02_statemachine.md)

Defines the intended navigation states:

```text
START

ACQUIRE

NORMAL

TARGET_ACQUIRE

AVOID

PASS_CONFIRM

RECOVER

CORNER

PARKING

STOP
```

The state machine answers:

> **What is Piolín currently trying to accomplish?**

This allows different controllers to receive authority at different times.

---

## 8.3 Wall Following

### [Wall Following](software_obstacles_strategy/03_wallfollowing.md)

Explains Piolín's use of:

```text
S2 LEFT

S3 RIGHT
```

as a geometric sensing pair rather than two independent threshold sensors.

Important ideas include:

```text
filtering

position estimation

geometry confidence

deadband

nonlinear correction

wall safety

state-dependent wall authority
```

A major architectural distinction is:

```text
NORMAL WALL CONTROL
≠
CRITICAL WALL SAFETY
```

---

## 8.4 Corner Handling

### [Corner Handling](software_obstacles_strategy/04_cornerhandling.md)

Documents how Piolín transitions between corridors.

The intended progression is:

```text
NORMAL
→ CORNER ENTRY
→ CORNER
→ CORNER EXIT
→ REACQUIRE
→ NORMAL
```

Corner handling deliberately reduces the authority of straight-corridor assumptions because S2/S3 geometry changes while the chassis rotates.

---

## 8.5 Obstacle Detection

### [Obstacle Detection](software_obstacles_strategy/05_obstacledetec.md)

Explains how raw Pixy detections become a meaningful target.

The intended process is:

```text
READ BLOCKS
→ VALIDATE
→ BUILD CANDIDATES
→ EVALUATE RELEVANCE
→ CONFIRM
→ LOCK
```

The obstacle rules are fixed:

```text
sig2
→ RED
→ PASS RIGHT
```

```text
sig3
→ GREEN
→ PASS LEFT
```

Camera position does **not** determine the passing rule.

---

## 8.6 Obstacle Strategy

### [Obstacle Strategy](software_obstacles_strategy/06_obstaclestrateg.md)

Describes the complete physical pillar maneuver:

```text
NORMAL
→ TARGET_ACQUIRE
→ APPROACH
→ AVOID
→ PASS_CONFIRM
→ RECOVER
→ NORMAL
```

During `AVOID`:

```text
Pixy obstacle objective
→ primary trajectory authority
```

while:

```text
S2/S3
→ physical context and critical wall safety
```

After the pillar is cleared, `RECOVER` deliberately restores useful track geometry.

---

## 8.7 Software Tuning

### [Software Tuning](software_obstacles_strategy/07_softwaretuning.md)

Defines the tuning philosophy:

```text
identify first incorrect layer

change one primary variable

repeat same test

compare

keep or reject
```

Important tuning categories include:

```text
speed

steering smoothing

target confirmation

target relevance

wall authority

obstacle steering

pass confirmation

recovery
```

The document emphasizes preserving a known-good baseline rather than modifying many parameters simultaneously.

---

## 8.8 Pixy2.1 Vision Software

### [Pixy2.1 Camera Vision](software_obstacles_strategy/08_CameraPXVision.md)

Explains Pixy2.1 as a perception subsystem.

The current signature mapping is:

```text
sig1 → Pink → Parking

sig2 → Red → PASS RIGHT

sig3 → Green → PASS LEFT
```

It documents:

```text
x / y / width / height

candidate validation

multiple-target selection

confirmation

target lock

temporary target loss

camera FOV

lighting

sensor fusion
```

The camera reports information.

The EV3 decides how that information affects the vehicle.

---

## 8.9 RGB Floor Detection

### [RGB Detection](software_obstacles_strategy/09_RGBdetection.md)

Documents the S4 floor-classification strategy.

The Color Sensor can use:

```text
reflection

R

G

B
```

to classify:

```text
BLUE

ORANGE

NONE
```

This subsystem is completely separate from Pixy's Red/Green obstacle classification.

```text
S4 RGB
→ floor

Pixy2.1
→ pillars / parking
```

Prototype RGB thresholds are documented as development parameters rather than final physical specifications.

---

## 8.10 Color Events and Lap Counting

### [Color and Lap Counting](software_obstacles_strategy/10_color_and_lap_counting.md)

Explains how continuous floor readings become discrete course events.

The pipeline is:

```text
CLASSIFY
→ CONFIRM
→ LATCH
→ COUNT
→ RELEASE
→ RE-ARM
```

The first confirmed course color can establish direction:

```text
BLUE first
→ COUNTERCLOCKWISE
```

```text
ORANGE first
→ CLOCKWISE
```

The current development model uses:

```text
12 accepted course events
```

as the intended progression reference for:

```text
3 laps / 12 corners
```

before parking becomes eligible.

---

# 9. Parking Subsystem

Parking is documented separately because it is a complete autonomous subsystem rather than a short final motor action.

Its intended architecture is:

```text
COURSE COMPLETE
      ↓
PARKING ELIGIBLE
      ↓
PINK CONFIRMED
      ↓
APPROACH
      ↓
ENTRY
      ↓
ALIGNMENT
      ↓
FINAL POSITION
      ↓
STOP
```

### [Parking Overview](software_obstacles_strategy/parking/01_ParkingOverview.md)

Introduces the complete parking architecture and sensor responsibilities.

### [Parking Algorithm](software_obstacles_strategy/parking/02_ParkingAlgorithm.md)

Defines:

```text
parking eligibility

Pink confirmation

target lock

APPROACH

ENTRY

ALIGN

FINAL

STOP
```

### [Parking Geometry](software_obstacles_strategy/parking/03_ParkingGeom.md)

Explains parking as an Ackermann vehicle-pose problem using:

```text
Pixy geometry

S2/S3 clearances

Motor A progression

Motor B steering state
```

Because Obstacles has no gyro installed, parking does not depend on direct absolute heading.

### [Parking Calibration](software_obstacles_strategy/parking/04_ParkingCalib.md)

Defines the calibration process:

```text
freeze hardware

verify sensors

calibrate Pink

establish repeatable approach

calibrate entry

freeze entry

calibrate alignment

calibrate final travel

define STOP tolerances
```

### [Parking Testing](software_obstacles_strategy/parking/05_Parkingtesting.md)

Explains how parking is validated from:

```text
individual phase tests

repeatability tests

variation tests

complete parking

full-course integration
```

No parking success percentage is treated as valid until supported by recorded physical trials.

---

# 10. Systems Engineering

The `systems_engineering/` section explains **why the robot became the system documented above**.

It records architecture evolution, trade-offs, constraints, failure modes, and lessons from approaches that were replaced.

This section is especially important because Piolín is not presented as a robot that was designed correctly on the first attempt.

It is presented as the result of an engineering process.

---

## 10.1 Engineering Process

### [Engineering Process](systems_engineering/01_engineeringprocess.md)

Documents the development cycle:

```text
observe

identify first failure

form hypothesis

change relevant subsystem

test

record

keep or reject

iterate
```

It also explains the evolution from:

```text
direct reactions
```

toward:

```text
layered sensing

state management

controller arbitration

repeatable testing
```

---

## 10.2 Decision Log

### [Engineering Decision Log](systems_engineering/02_decisionlog.md)

Records major architecture decisions such as:

```text
Ackermann steering

round-specific S1

Gyro in Open

Pixy2.1 in Obstacles

two lateral ultrasonics

state-based software

signature-based Red/Green rule

progress-gated parking

legacy separation
```

Each decision is documented in terms of:

```text
problem

alternatives

reasoning

trade-off

current result
```

---

## 10.3 Design Constraints

### [Design Constraints](systems_engineering/03_designconstraints.md)

Explains limitations that shape the system, including:

```text
EV3 port availability

Ackermann motion

lack of gyro in Obstacles

no permanent front ultrasonic

camera field of view

lighting

single steering actuator

physical course progression

software-environment differences
```

The design is intentionally based on the hardware Piolín actually has rather than capabilities that would be convenient but are unavailable.

---

## 10.4 Engineering Trade-Offs

### [Engineering Trade-Offs](systems_engineering/04_tradeoffs.md)

Documents compromises such as:

```text
Ackermann predictability
vs.
ability to rotate in place
```

```text
target confirmation
vs.
reaction delay
```

```text
steering smoothing
vs.
responsiveness
```

```text
higher speed
vs.
control margin
```

```text
more sensors
vs.
system complexity
```

```text
sensor-fused parking
vs.
software simplicity
```

The goal is system performance rather than optimizing one subsystem independently.

---

## 10.5 Risks and Mitigation

### [Risks and Mitigation](systems_engineering/05_risksandmitigation.md)

Maintains a qualitative risk register for failures such as:

```text
steering-center errors

S2/S3 inversion

ultrasonic spikes

Pixy target loss

target switching

controller conflict

incorrect state transitions

duplicate course counts

early parking

software regression
```

Mitigations include:

```text
validation

filtering

confirmation

locking

state guards

controller arbitration

critical safety

bounded commands

telemetry

known-good baselines
```

---

## 10.6 What Did Not Work

### [What Did Not Work](systems_engineering/06_whatdidntwork.md)

Documents approaches that were replaced or proved insufficient.

Examples include:

```text
HuskyLens + Arduino Nano active architecture

trying to keep too many sensors active

ambiguous ultrasonic identities

simple threshold-only wall reactions

wall following fighting pillar avoidance

direct camera-to-steering

image position determining passing side

first Pixy block wins

releasing a pillar immediately after visual loss

counting every S4 sample

timing-only maneuver completion

changing many tuning variables simultaneously

full-course testing too early
```

The purpose is to preserve engineering lessons rather than hide unsuccessful development.

---

# 11. Reproducibility

The `reproducibility/` section explains how the documented robot can be reconstructed, configured, calibrated, and tested.

The goal is:

> **Another technically capable reader should be able to understand what must be connected, which configuration is active, how the software should be prepared, and how calibration should be repeated.**

### [Reproducibility Overview](reproducibility/01_ReproducibilityOverview.md)

Introduces the complete reconstruction philosophy.

### [Wiring](reproducibility/03_wiring.md)

Documents:

```text
motor ports

sensor ports

Open wiring

Obstacle wiring

round-specific S1
```

### [Electrical Schematic](reproducibility/04_elecschem.md)

Explains the electrical relationships between:

```text
EV3

battery

motors

sensors

Pixy2.1
```

### [Software Setup](reproducibility/05_softwaresetup.md)

Documents the software environments and setup required for the current programs.

The main distinction is:

```text
Open
→ Pybricks MicroPython
```

```text
Obstacles
→ current direct Pixy integration through ev3dev2 + SMBus/I2C
```

### [Calibration Procedure](reproducibility/06_HowToCalibrate.md)

Explains how calibration should be repeated after relevant hardware changes.

### [Testing Protocol](reproducibility/07_TestingProtocol.md)

Defines a structured progression from:

```text
component tests
```

to:

```text
subsystem tests
```

to:

```text
full-course integration
```

### [Troubleshooting](reproducibility/08_Troubleshooting.md)

Provides a diagnostic process based on finding the first incorrect layer in:

```text
SENSING

INTERPRETATION

STATE

CONTROLLER

FINAL COMMAND

PHYSICAL RESPONSE
```

---

# 12. Current vs. Legacy Architecture

A critical documentation rule is that earlier prototypes are not presented as current hardware.

The current system is:

```text
OPEN

S1 Gyro
S2 LEFT US
S3 RIGHT US
S4 Color
```

and:

```text
OBSTACLES

S1 Pixy2.1
S2 LEFT US
S3 RIGHT US
S4 Color
```

Earlier experiments involving systems such as:

```text
HuskyLens

Arduino Nano

different camera interfaces

different sensor arrangements
```

are useful engineering evidence but should be understood as:

```text
LEGACY DEVELOPMENT
```

rather than current competition architecture.

This distinction allows the repository to preserve design history without making the current robot ambiguous.

---

# 13. Key Software Principles

Across the software documentation, several principles appear repeatedly.

### Validate before acting

```text
sensor value
→ validate
→ interpret
```

not:

```text
sensor value
→ immediate steering
```

### Convert samples into events

```text
candidate
→ confirm
→ lock
→ release
```

is used for both:

```text
floor landmarks

obstacle targets
```

### Keep sensor responsibilities clear

```text
Pixy
→ object identity / forward geometry
```

```text
S2/S3
→ lateral physical geometry
```

```text
S4
→ floor/course state
```

### Use the state machine to assign control authority

```text
NORMAL
→ wall geometry

AVOID
→ obstacle controller

CORNER
→ corner controller

RECOVER
→ recovery controller

PARKING
→ parking controller
```

### Keep safety independent

Critical wall protection can override an otherwise valid maneuver if the physical trajectory becomes unsafe.

### Use physical evidence when possible

The architecture increasingly favors:

```text
sensor geometry

course events

encoder progression
```

over timing alone.

---

# 14. Key Engineering Principles

The documentation also reflects several broader PiolínTech engineering rules.

```text
Do not change several unrelated parameters at once.
```

```text
Do not diagnose only from the final collision.
```

```text
Find the first layer where behavior becomes incorrect.
```

```text
Preserve a known-good software baseline.
```

```text
Distinguish current architecture from legacy prototypes.
```

```text
Do not publish old measurements as current specifications.
```

```text
Do not describe temporary calibration values as universal constants.
```

```text
Test subsystems before full-course integration.
```

```text
Use video, telemetry, test notes, and Git history together.
```

These practices are as important to the project as the individual control equations.

---

# 15. Suggested Reading Order

For a first-time technical reviewer, the recommended path is:

```text
1. Project Overview
        ↓
2. Hardware Overview
        ↓
3. Mobility / Steering
        ↓
4. Power & Sensors
        ↓
5. Software Architecture
        ↓
6. State Machine
        ↓
7. Obstacle Detection + Strategy
        ↓
8. Parking
        ↓
9. Systems Engineering
        ↓
10. Reproducibility
```

Direct links:

1. [Project Overview](project_overview/01_ProjectOverview.md)
2. [Hardware Overview](components/01_Hardwareoverview.md)
3. [Robot Mobility](mobility_mechanical/03_RMobility.md)
4. [Power and Sensor Configuration](power_sensors/01_PowerSensorconfig.md)
5. [Software Architecture](software_obstacles_strategy/01_SWArchitecture.md)
6. [State Machine](software_obstacles_strategy/02_statemachine.md)
7. [Obstacle Strategy](software_obstacles_strategy/06_obstaclestrateg.md)
8. [Parking Overview](software_obstacles_strategy/parking/01_ParkingOverview.md)
9. [Engineering Process](systems_engineering/01_engineeringprocess.md)
10. [Reproducibility Overview](reproducibility/01_ReproducibilityOverview.md)

A reader interested in one specific subsystem can instead enter directly through the relevant section above.

---

# 16. Documentation and WRO Engineering Criteria

The documentation is organized to provide evidence across the main engineering areas evaluated in the project.

| Engineering Area | Main Documentation |
| :--- | :--- |
| Mobility & Mechanical Design | `mobility_mechanical/`, `components/03–04` |
| Power & Sensors | `power_sensors/`, `components/05–09` |
| Software Architecture & Obstacle Avoidance | `software_obstacles_strategy/` |
| Systems Thinking & Engineering Decisions | `systems_engineering/` |
| Reproducibility & Repository Quality | `reproducibility/`, this documentation index |

No single file is intended to carry the complete engineering explanation.

Instead:

```text
MECHANICS
+
HARDWARE
+
SENSING
+
SOFTWARE
+
TESTING
+
DECISION HISTORY
```

together describe the complete Piolín system.

---

# 17. Current Development Status

Several parts of Piolín's architecture are already clearly established.

### Established architecture

```text
EV3 controller

Motor A propulsion

Motor B Ackermann steering

S2 LEFT

S3 RIGHT

S4 Color Sensor

Gyro on S1 during Open

Pixy2.1 on S1 during Obstacles

sig1 Pink

sig2 Red

sig3 Green

Red → PASS RIGHT

Green → PASS LEFT

state-based control architecture

progress-gated parking
```

### Still under active calibration

```text
final obstacle target-relevance equation

final obstacle steering profiles

pass-confirmation thresholds

recovery parameters

corner transition thresholds

final RGB thresholds

parking entry geometry

parking alignment

final parking encoder progression

final parking tolerances
```

The repository intentionally distinguishes:

```text
ARCHITECTURE DECIDED
```

from:

```text
CALIBRATION FINISHED
```

because an engineering system can have a stable design while still requiring numerical tuning.

---

# 18. Final Documentation Overview

PiolínTech's documentation is designed to answer four levels of questions.

### Level 1 — What is the robot?

Answered by:

```text
project overview

hardware overview

components
```

### Level 2 — How does it work?

Answered by:

```text
mobility

power and sensors

software architecture

parking
```

### Level 3 — Why was it designed this way?

Answered by:

```text
engineering process

decision log

constraints

trade-offs

risks

what did not work
```

### Level 4 — Can the result be reproduced?

Answered by:

```text
wiring

software setup

calibration

testing

troubleshooting

Git documentation
```

Together, these sections document Piolín not only as a finished competition vehicle, but as an engineering system whose:

```text
requirements

architecture

experiments

failures

decisions

control logic

calibration

testing
```

can be followed from early development to the current design.

The central documentation principle is:

> **A strong engineering repository should make it possible to understand not only what the robot does, but also how the subsystems interact, why the design evolved in its current direction, which limitations remain, and how the complete system can be reconstructed and tested.**

---

<div align="center">

### [← Back to PiolínTech Main README](../README.md)

</div>

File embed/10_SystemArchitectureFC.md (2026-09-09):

# Piolín System Architecture Flowchart

This flowchart represents Piolín's **complete autonomous-system architecture** for WRO Future Engineers 2026.

The architecture is organized as a layered control system rather than as a direct collection of sensor-to-motor reactions.

The general structure is:

```text
ENVIRONMENT
    ↓
SENSORS
    ↓
INPUT VALIDATION
    ↓
PERCEPTION / GEOMETRY
    ↓
STATE MACHINE
    ↓
ACTIVE CONTROLLER
    ↓
CONTROL ARBITRATION
    ↓
ACTUATION
    ↓
PHYSICAL VEHICLE
    ↓
NEW SENSOR FEEDBACK
```

The same mechanical vehicle is used in both competition rounds, while the S1 sensor changes according to the task.

---

## Complete System Architecture

```mermaid
flowchart TD

    ENV([WRO COURSE ENVIRONMENT])

    %% ROUND CONFIGURATION

    ROUND{"Competition round?"}

    OPEN["OPEN CONFIGURATION<br/><br/>S1 = EV3 Gyro Sensor"]

    OBST["OBSTACLE CONFIGURATION<br/><br/>S1 = Pixy2.1"]

    %% COMMON SENSORS

    S2["S2<br/>LEFT Ultrasonic Sensor"]

    S3["S3<br/>RIGHT Ultrasonic Sensor"]

    S4["S4<br/>Downward EV3 Color Sensor"]

    GYRO["S1 Gyro<br/><br/>Heading / turn information"]

    PIXY["S1 Pixy2.1<br/><br/>Forward color-object perception"]

    %% ACQUISITION

    ACQUIRE["SENSOR ACQUISITION"]

    US_READ["Read S2 / S3<br/>lateral distances"]

    COLOR_READ["Read S4<br/><br/>Reflection<br/>RGB / floor class"]

    GYRO_READ["Read Gyro angle / heading"]

    PIXY_READ["Read Pixy blocks<br/><br/>signature<br/>x<br/>y<br/>width<br/>height"]

    %% VALIDATION

    VALIDATE["INPUT VALIDATION"]

    US_VALID["Ultrasonic validation<br/>+ short filtering"]

    COLOR_VALID["Floor classification<br/>+ candidate validation"]

    GYRO_VALID["Gyro processing<br/>and heading reference"]

    PIXY_VALID["Pixy block validation<br/>and candidate filtering"]

    %% PERCEPTION

    PERCEPTION["PERCEPTION / GEOMETRY"]

    WALL_GEOM["Lateral geometry estimation<br/><br/>S2 + S3"]

    COLOR_EVENT["Floor-event processing<br/><br/>Confirm<br/>Latch<br/>Count<br/>Release"]

    HEADING["Heading stabilization<br/>and corner support"]

    VISION["Vision processing<br/><br/>Validate<br/>Rank<br/>Confirm<br/>Lock"]

    %% INFORMATION

    COURSE_STATE["COURSE STATE<br/><br/>Direction<br/>Progress count<br/>Parking eligibility"]

    TARGET["ACTIVE VISUAL TARGET<br/><br/>Pink / Red / Green<br/>Image geometry<br/>Target lock"]

    GEOMETRY["PHYSICAL GEOMETRY<br/><br/>Left clearance<br/>Right clearance<br/>Estimated track relationship"]

    %% STATE MACHINE

    STATE["NAVIGATION STATE MACHINE"]

    START["START / ACQUIRE"]

    NORMAL["NORMAL"]

    TARGET_ACQ["TARGET_ACQUIRE"]

    AVOID["AVOID"]

    PASS["PASS_CONFIRM"]

    RECOVER["RECOVER"]

    CORNER["CORNER"]

    PARKING["PARKING"]

    STOP["STOP"]

    %% CONTROLLERS

    CTRL["STATE-DEPENDENT CONTROLLERS"]

    NORMAL_CTRL["Normal wall / course controller"]

    TARGET_CTRL["Stable target-acquisition controller"]

    AVOID_CTRL["Pillar-avoidance controller<br/><br/>Red → RIGHT<br/>Green → LEFT"]

    PASS_CTRL["Pass-confirmation controller"]

    RECOVER_CTRL["Recovery controller"]

    CORNER_CTRL["Corner controller"]

    PARK_CTRL["Parking controller<br/><br/>Approach<br/>Entry<br/>Align<br/>Final"]

    STOP_CTRL["Terminal stop command"]

    %% SAFETY

    SAFETY["CRITICAL WALL SAFETY"]

    SAFETY_CHECK{"Unsafe physical<br/>wall proximity?"}

    SAFETY_CMD["Safety steering command<br/>+ reduced speed"]

    %% ARBITRATION

    ARBITRATION["CONTROL ARBITRATION<br/><br/>Safety<br/>→ Active maneuver<br/>→ Normal navigation"]

    LIMIT["Clamp steering request"]

    SMOOTH["Steering-target smoothing"]

    SPEED["State-dependent speed selection"]

    %% MOTORS

    MOTOR_B["Motor B<br/>EV3 Medium Motor<br/>Ackermann steering"]

    MOTOR_A["Motor A<br/>EV3 Large Motor<br/>Rear propulsion"]

    %% MECHANICS

    ACK["Front Ackermann mechanism"]

    DRIVE["Rear drivetrain"]

    VEHICLE["PIOLÍN PHYSICAL MOTION"]

    %% FEEDBACK

    STEER_FB["Motor B encoder<br/>Actual steering position"]

    DRIVE_FB["Motor A encoder<br/>Vehicle progression"]

    LOOP([NEXT CONTROL CYCLE])

    %% ENVIRONMENT / CONFIGURATION

    ENV --> ROUND

    ROUND -- "Open" --> OPEN
    ROUND -- "Obstacles" --> OBST

    OPEN --> GYRO
    OBST --> PIXY

    ENV --> S2
    ENV --> S3
    ENV --> S4

    %% SENSOR ACQUISITION

    S2 --> US_READ
    S3 --> US_READ
    S4 --> COLOR_READ
    GYRO --> GYRO_READ
    PIXY --> PIXY_READ

    US_READ --> ACQUIRE
    COLOR_READ --> ACQUIRE
    GYRO_READ --> ACQUIRE
    PIXY_READ --> ACQUIRE

    %% VALIDATION

    ACQUIRE --> VALIDATE

    VALIDATE --> US_VALID
    VALIDATE --> COLOR_VALID

    OPEN --> GYRO_VALID
    GYRO_READ --> GYRO_VALID

    OBST --> PIXY_VALID
    PIXY_READ --> PIXY_VALID

    %% PERCEPTION

    US_VALID --> WALL_GEOM
    COLOR_VALID --> COLOR_EVENT
    GYRO_VALID --> HEADING
    PIXY_VALID --> VISION

    WALL_GEOM --> GEOMETRY
    COLOR_EVENT --> COURSE_STATE
    HEADING --> STATE
    VISION --> TARGET

    %% STATE INPUTS

    GEOMETRY --> STATE
    COURSE_STATE --> STATE
    TARGET --> STATE

    STEER_FB --> STATE
    DRIVE_FB --> STATE

    %% STATE MACHINE

    STATE --> START
    STATE --> NORMAL
    STATE --> TARGET_ACQ
    STATE --> AVOID
    STATE --> PASS
    STATE --> RECOVER
    STATE --> CORNER
    STATE --> PARKING
    STATE --> STOP

    %% CONTROLLERS

    START --> NORMAL_CTRL
    NORMAL --> NORMAL_CTRL
    TARGET_ACQ --> TARGET_CTRL
    AVOID --> AVOID_CTRL
    PASS --> PASS_CTRL
    RECOVER --> RECOVER_CTRL
    CORNER --> CORNER_CTRL
    PARKING --> PARK_CTRL
    STOP --> STOP_CTRL

    NORMAL_CTRL --> CTRL
    TARGET_CTRL --> CTRL
    AVOID_CTRL --> CTRL
    PASS_CTRL --> CTRL
    RECOVER_CTRL --> CTRL
    CORNER_CTRL --> CTRL
    PARK_CTRL --> CTRL
    STOP_CTRL --> CTRL

    %% SAFETY

    GEOMETRY --> SAFETY
    SAFETY --> SAFETY_CHECK

    SAFETY_CHECK -- "YES" --> SAFETY_CMD
    SAFETY_CHECK -- "NO" --> ARBITRATION

    CTRL --> ARBITRATION
    SAFETY_CMD --> ARBITRATION

    %% FINAL COMMAND

    ARBITRATION --> LIMIT
    LIMIT --> SMOOTH

    STATE --> SPEED

    SMOOTH --> MOTOR_B
    SPEED --> MOTOR_A

    %% PHYSICAL ACTUATION

    MOTOR_B --> ACK
    MOTOR_A --> DRIVE

    ACK --> VEHICLE
    DRIVE --> VEHICLE

    %% FEEDBACK

    MOTOR_B --> STEER_FB
    MOTOR_A --> DRIVE_FB

    VEHICLE --> ENV

    STEER_FB --> LOOP
    DRIVE_FB --> LOOP
    LOOP --> ACQUIRE
```

---

## 1. Same Vehicle, Two Sensor Configurations

Piolín uses one common mechanical platform for both WRO rounds.

The shared architecture is:

```text
EV3 Brick

Motor A propulsion

Motor B steering

S2 LEFT ultrasonic

S3 RIGHT ultrasonic

S4 Color Sensor
```

Only S1 changes.

### Open Challenge

```text
S1
→ EV3 Gyro Sensor
```

### Obstacle Challenge

```text
S1
→ Pixy2.1
```

The Gyro Sensor and Pixy2.1 are therefore not simultaneously active in the current architecture.

---

## 2. Sensor Layer

The sensor layer collects information from the physical course.

### S2

```text
LEFT Ultrasonic Sensor
```

provides information about:

```text
left physical clearance

track geometry

wall safety
```

### S3

```text
RIGHT Ultrasonic Sensor
```

provides equivalent information on the opposite side.

The permanent convention is:

```text
S2 = LEFT

S3 = RIGHT
```

These physical identities do not change with course direction.

---

### S4

The downward Color Sensor provides floor information.

Its roles include:

```text
Blue / Orange detection

initial course direction

course progression

corner context

parking eligibility
```

It does not identify Red and Green pillars.

---

### Gyro

During Open:

```text
S1 = Gyro
```

The Gyro Sensor provides:

```text
heading stabilization

drift information

turn progression

corner support
```

---

### Pixy2.1

During Obstacles:

```text
S1 = Pixy2.1
```

Pixy provides forward visual information.

The current signature mapping is:

```text
sig1
→ PINK
→ Parking
```

```text
sig2
→ RED
→ PASS RIGHT
```

```text
sig3
→ GREEN
→ PASS LEFT
```

Useful block information includes:

```text
signature

x

y

width

height
```

---

## 3. Sensor Acquisition

The EV3 first gathers raw information.

Conceptually:

```text
READ SENSORS
      ↓
store latest measurements
```

The purpose of acquisition is only to obtain data.

The sensor-reading layer should not directly decide:

```text
which obstacle to pass

which state should run

which direction Motor B should steer
```

Those decisions occur later.

---

## 4. Input Validation

Raw sensor values are not automatically trusted.

Piolín applies validation before using them in control.

Examples include:

```text
ultrasonic range checking

short ultrasonic filtering

floor-color classification

Pixy block filtering

candidate validation
```

The intended principle is:

```text
RAW INPUT
→ VALIDATED INPUT
```

before:

```text
navigation decision
```

---

## 5. Ultrasonic Geometry

S2 and S3 are interpreted together.

The wall subsystem asks:

```text
What is Piolín's current lateral relationship
with the surrounding geometry?
```

rather than only:

```text
Is one sensor too close?
```

The result can contribute to:

```text
normal wall following

critical wall safety

pillar pass confirmation

recovery

parking
```

The same measurements can have different importance depending on the navigation state.

---
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

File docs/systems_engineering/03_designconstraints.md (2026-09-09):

# 3. Design Constraints

<div align="center">

Top view of Piolín showing the compact vehicle architecture

<br>

<sub><b>Figure 3.1.</b> Piolín's final architecture is shaped by interacting mechanical, sensing, electrical, software, and course constraints.</sub>

</div>

Every engineering design is created inside a set of constraints.

Piolín is no exception.

The robot cannot be designed only around the question:
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

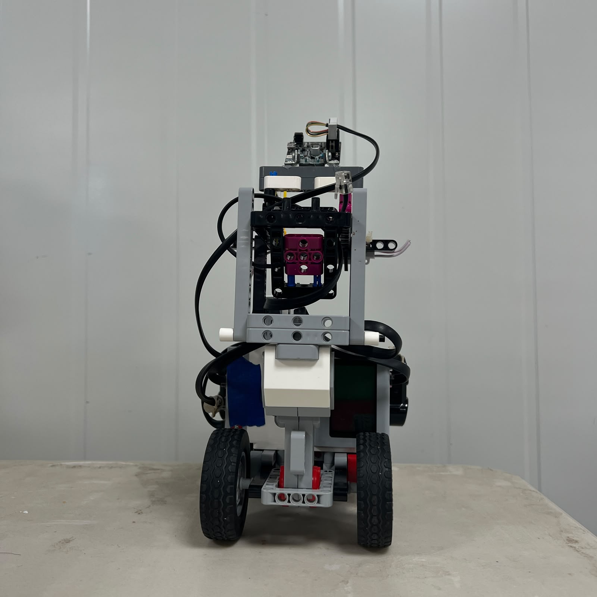
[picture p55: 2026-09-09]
v-photos/v4/chassis_rear.jpg

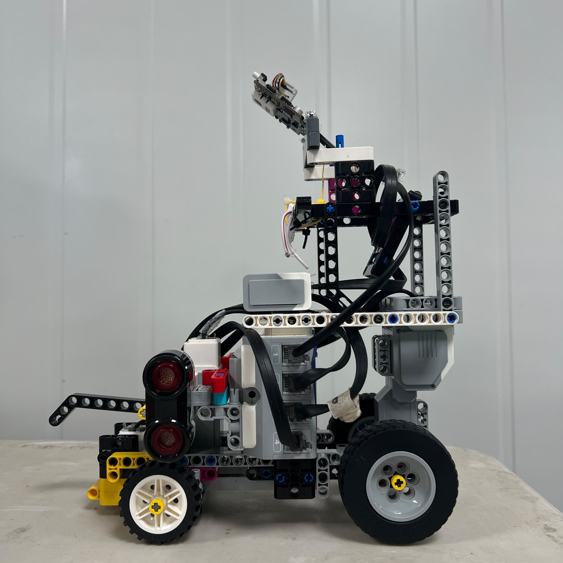
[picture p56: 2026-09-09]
v-photos/v4/chassis_left.jpg

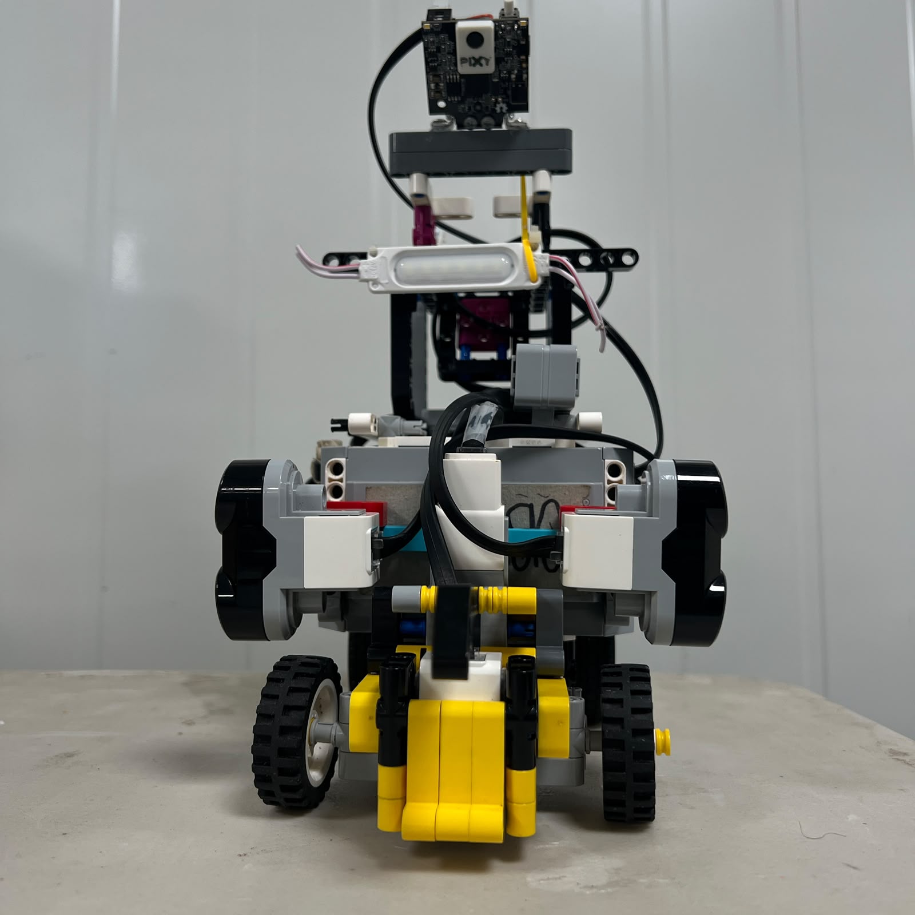
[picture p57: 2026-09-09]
v-photos/v4/chassis_front.jpg

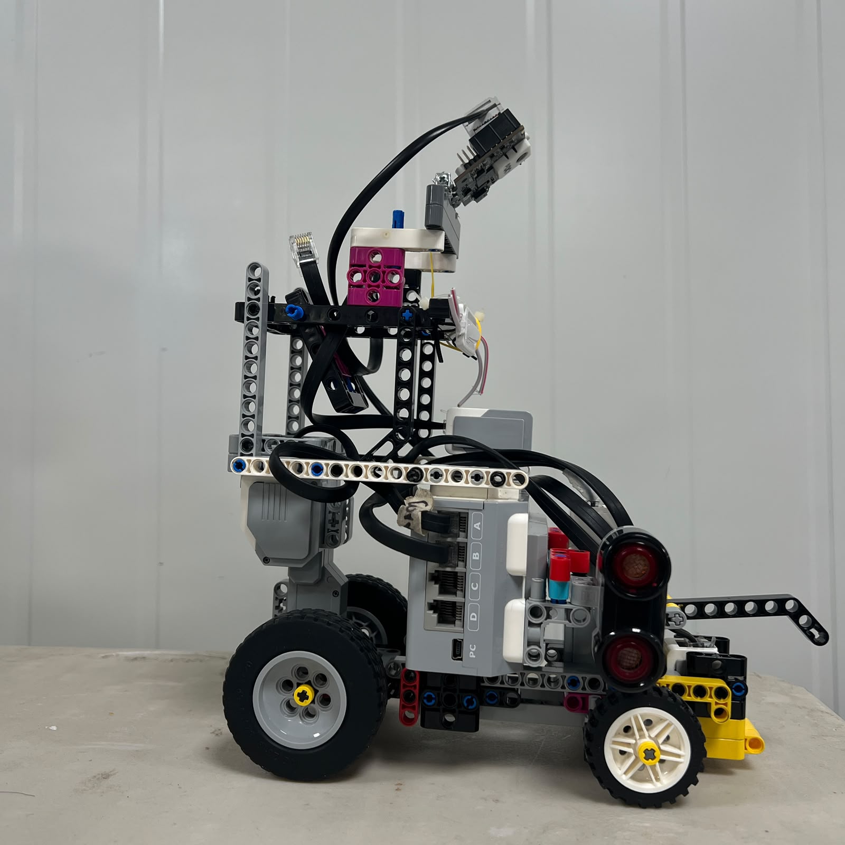
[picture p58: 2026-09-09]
v-photos/v4/chassis_right.jpg

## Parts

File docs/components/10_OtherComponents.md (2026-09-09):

# 10. Other Structural and Supporting Components

<div align="center">

Top view of Piolín's LEGO Technic chassis

<br>

<sub><b>Figure 10.1.</b> Top view of Piolín's current LEGO Technic chassis and the structural integration of its main subsystems.</sub>

</div>

Piolín's autonomous system depends on more than its controller, motors, and sensors. A large part of the robot's reliability comes from the **structural and supporting components** that hold those systems in repeatable positions.

The current vehicle is built primarily from **LEGO Technic structural elements**, including beams, axles, pins, connectors, wheel assemblies, and mounting structures.

These components perform several important functions:

```text
support the EV3

support the battery

hold Motor A

hold Motor B

maintain Ackermann steering geometry

support the wheel assemblies

hold the ultrasonic sensors

hold the Color Sensor

support the round-specific S1 device

route cables away from moving mechanisms
```

Although these pieces do not directly execute autonomous decisions, they strongly influence whether the sensors and actuators behave consistently.

A good software controller cannot fully compensate for a chassis that changes geometry between runs.

---

## 10.1 LEGO Technic Chassis

The current Piolín platform uses a LEGO Technic frame to connect the vehicle's main systems into one rigid mechanical structure.

The chassis must support:

```text
EV3 Brick

Rechargeable Battery

Large Motor

Medium Motor

rear drivetrain

front steering system

ultrasonic sensors

Color Sensor

Gyro or Pixy2.1
```

while keeping these components in predictable positions.

The chassis therefore serves as the mechanical reference frame for almost every calibration performed on the robot.

For example:

```text
gyro orientation
```

is meaningful relative to the chassis.

```text
ultrasonic direction
```

is meaningful relative to the chassis.

```text
camera orientation
```

is meaningful relative to the chassis.

```text
steering center
```

is also defined relative to the chassis.

This makes structural consistency part of the sensing and control system.

---

## 10.2 Chassis Rigidity

<div align="center">

Bottom view of Piolín's current chassis

<br>

<sub><b>Figure 10.2.</b> Bottom view of the current chassis, showing the structural relationships between the drivetrain, front steering assembly, and central frame.</sub>

</div>

A chassis does not need to be perfectly rigid, but excessive flex can reduce repeatability.

Suppose the front structure moves slightly under steering load.

```text
Motor B rotates
      ↓
steering structure flexes
      ↓
part of motor motion becomes chassis deformation
      ↓
wheel angle differs from expected value
```

The same problem can occur around sensor mounts.

```text
sensor mount flexes
      ↓
sensor orientation changes
      ↓
measurement geometry changes
```

For this reason, Piolín's structural design aims to reduce unnecessary movement around:

```text
steering pivots

motor mounts

sensor mounts

axles

EV3 mounting points
```

before software calibration is performed.

---

## 10.3 Why Structural Repeatability Matters

Many autonomous-navigation parameters assume that the physical robot remains approximately unchanged.

For example, Open navigation assumes that:

```text
S2 remains LEFT

S3 remains RIGHT

Gyro orientation remains fixed

Color Sensor remains at the same floor position
```

Obstacle navigation assumes that:

```text
Pixy remains at the same viewing orientation

ultrasonic mounts remain stable

steering geometry remains repeatable
```

If the physical structure changes, previously tuned software values may no longer describe the same vehicle.

Therefore:

> **Mechanical repeatability is a prerequisite for meaningful software calibration.**

---

# 10.4 Motor A Mounting

<div align="center">

Piolín Motor A mounting structure

<br>

<sub><b>Figure 10.3.</b> Mounting structure used to secure the EV3 Large Motor that powers Piolín's rear drivetrain.</sub>

</div>

Motor A produces the force required to move the complete robot.

Its mounting structure must therefore prevent unnecessary motion between:

```text
Large Motor

drivetrain

chassis
```

If the motor shifts relative to the drivetrain:

```text
gear / axle alignment may change

friction may increase

mechanical efficiency may decrease

encoder movement may become less repeatable
```

The motor mount is therefore part of the propulsion system rather than simply a structural accessory.

---

# 10.5 Motor B Mounting

<div align="center">

Piolín Motor B steering-motor mounting structure

<br>

<sub><b>Figure 10.4.</b> Structural mounting of the EV3 Medium Motor used to actuate Piolín's front steering system.</sub>

</div>

Motor B requires an especially stable mount because its output is interpreted as a steering-position reference.

If the motor housing moves while the output shaft rotates:

```text
encoder position changes
```

but not all of that movement becomes:

```text
wheel steering
```

The mounting structure should therefore resist:

```text
rotation

flex

movement under steering load
```

so that Motor B position corresponds as consistently as possible to the installed linkage position.

The detailed steering geometry is documented separately in [Steering Motor and Ackermann Actuation](04_SteeringMotor.md).

---

# 10.6 Axles and Rotational Support

LEGO axles transmit motion through both the drivetrain and steering systems.

Their alignment influences:

```text
friction

wheel rotation

drivetrain efficiency

steering response
```

An axle that is slightly forced out of alignment can create unnecessary resistance.

For propulsion:

```text
motor torque
      ↓
axle / drivetrain
      ↓
rear wheel motion
```

For steering:

```text
Motor B
      ↓
steering linkage
      ↓
wheel pivot motion
```

The mechanical system should therefore be checked for free movement before increasing software motor commands.

---

# 10.7 Pins and Connectors

LEGO Technic pins and connectors form the structural joints of Piolín.

They provide a modular construction system, but each connection also introduces some mechanical clearance.

Possible consequences include:

```text
small chassis flex

steering backlash

mounting movement

sensor-angle variation
```

The objective is not to claim that LEGO connections have zero play.

Instead, the chassis is arranged so that important assemblies are supported by enough structure to remain consistent under normal competition movement.

---

# 10.8 Wheel Assemblies

Piolín uses separate front and rear wheel roles.

```text
FRONT WHEELS
→ steering

REAR WHEELS
→ propulsion
```

The wheel assemblies influence:

```text
traction

turning radius

vehicle speed

encoder-to-distance relationship

ground clearance

mechanical load
```

The exact current V4 wheel diameters should be physically remeasured before being published as final specifications.

Older measurements from previous robot versions should not automatically be reused.

---

# 10.9 Rear Wheels

The rear wheels receive propulsion through Motor A and the drivetrain.

Their mechanical condition can influence:

```text
vehicle acceleration

straight-line behavior

traction

encoder-based displacement
```

Differences in wheel mounting or friction between the two sides can create an apparent navigation problem even when Motor A receives the correct software command.

Before tuning drive behavior, both rear wheels should therefore be checked for:

```text
free rotation

secure mounting

similar alignment

no chassis rubbing
```

---

# 10.10 Front Wheels

The front wheels belong to the Ackermann-style steering system.

Their mounting influences:

```text
steering geometry

mechanical center

turning radius

left/right symmetry
```

They must rotate freely while also pivoting through the steering mechanism.

A wheel that rubs against the structure during stronger steering can change the trajectory and increase Motor B load.

Therefore steering tests should check the mechanism at:

```text
center

left steering

right steering
```

rather than only when the wheels are straight.

---

# 10.11 Wheel and Axle Inspection

A simple mechanical check before major testing is:

```text
1. Lift the vehicle slightly.

2. Rotate rear wheels manually.

3. Check for rubbing or unusual resistance.

4. Move steering toward the left.

5. Check front-wheel clearance.

6. Return to center.

7. Move steering toward the right.

8. Check front-wheel clearance again.

9. Verify no axle or wheel is visibly loose.
```

This prevents software tuning from compensating for a mechanical condition that can be corrected directly.

---

# 10.12 Ultrasonic Sensor Mounts

The two lateral ultrasonic sensors remain permanently installed.

```text
S2 = LEFT

S3 = RIGHT
```

Their mounting geometry is especially important because the navigation system interprets their readings as track-relative distance information.

A small sensor rotation changes the direction in which distance is measured.

Therefore the mounts should preserve:

```text
lateral orientation

height

position relative to chassis

left/right identity
```

The detailed ultrasonic geometry is documented in [Ultrasonic Sensors](05_UltrasonicSensors.md).

---

# 10.13 Color Sensor Mount

The Color Sensor is permanently connected to S4 and faces the course surface.

Its mounting determines:

```text
sensor-to-floor distance

location at which a marking is detected

optical geometry

timing of course events
```

A loose vertical mount can change the sensor's optical response.

A loose longitudinal mount can change when the robot detects a floor marking relative to the rest of the chassis.

For this reason, the Color Sensor is treated as a fixed mechanical reference rather than as a freely repositioned accessory.

---

# 10.14 Custom Color Sensor Casing

<div align="center">

Piolín custom light-isolation casing around the EV3 Color Sensor

<br>

<sub><b>Figure 10.5.</b> Custom Color Sensor casing used to reduce uncontrolled ambient-light variation at the floor measurement area.</sub>

</div>

Piolín uses a custom casing around the downward-facing Color Sensor.

Its purpose is primarily optical rather than structural.

Without isolation:

```text
ambient light

side reflections

shadows
```

can contribute to the measurement environment.

The casing helps create a more controlled region around the sensor.

This illustrates an important engineering principle:

```text
sensor performance
=
sensor hardware
+
mechanical mounting
+
measurement environment
+
software
```

Improving the physical measurement environment can reduce the burden placed on software classification.

---

# 10.15 3D-Printed Components

The Color Sensor casing is one of the custom supporting components developed for Piolín.

The repository contains its printable model:

[Color Sensor Casing STL](../../models/3dprint/ColorSensorCasing.stl)

Providing the model improves reproducibility because another team can reproduce the same general light-isolation concept rather than reconstructing it only from photographs.

However, printing method and material can affect the final physical dimensions slightly.

The printed part should therefore still be checked on the assembled sensor.

---

# 10.16 Round-Specific S1 Mounting

Piolín's S1 device changes between rounds.

### Open

```text
S1
→ EV3 Gyro Sensor
```

### Obstacles

```text
S1
→ Pixy2.1
```

This means the supporting structure must allow the vehicle to use different sensing hardware while preserving the same main platform.

The modularity is primarily electrical and sensing-related rather than requiring a complete chassis rebuild.

---

# 10.17 Gyro Mounting Requirements

During Open, the Gyro Sensor must remain mechanically fixed relative to the chassis.

If the sensor rotates physically:

```text
same vehicle heading
```

can correspond to:

```text
different sensor orientation
```

which reduces the usefulness of gyro calibration.

The gyro mount should therefore maintain a repeatable orientation throughout the run.

The exact orientation is documented by the current V4 hardware evidence rather than inferred from older configurations.

---

# 10.18 Pixy2.1 Mounting Requirements

During Obstacles, Pixy2.1 must remain stable relative to the vehicle.

Camera geometry depends on:

```text
height

pitch

yaw

lateral offset
```

If the camera moves between tests, a pillar can appear at different image coordinates even when the physical scene is similar.

Therefore the Pixy mounting system is part of vision calibration.

The camera should also remain clear of:

```text
steering mechanism

moving cables

structural obstruction
```

that could reduce its useful field of view.

---

# 10.19 Cable and Connector Components

Piolín uses LEGO EV3 cables for its LEGO motors and sensors, while the Pixy2.1 uses its current S1 connection in the Obstacle configuration.

Cables perform an electrical role, but their physical routing is also a mechanical design issue.

Poor routing can create:

```text
steering interference

wheel interference

connector strain

moving cable loops

intermittent disconnection
```

Therefore cable placement must be checked under actual movement.

---

# 10.20 Cable Clearance Around Steering

Motor B moves the front steering mechanism through a usable range.

A cable may appear safe when the wheels are centered but interfere when they turn.

Cable clearance should therefore be checked at:

```text
LEFT
CENTER
RIGHT
```

If a cable becomes tensioned at one steering extreme, it can:

```text
resist Motor B

move a sensor

pull on a connector

change steering response
```

Cable routing is therefore part of mechanical reliability.

---

# 10.21 Cable Clearance Around the Drivetrain

The rear drivetrain also contains rotating components.

Cables should remain away from:

```text
axles

wheels

rotating drivetrain elements
```

A cable touching a moving drivetrain can cause:

```text
mechanical drag

cable damage

intermittent motion

unexpected load
```

The safest routing keeps wiring mechanically separated from the vehicle's moving transmission.

---

# 10.22 Fasteners and Structural Checks

Because Piolín is repeatedly:

```text
carried

tested

reconfigured

transported
```

structural connections can gradually loosen.

A simple inspection should check:

```text
motor mounts

sensor mounts

steering pivots

wheel mounts

EV3 support

camera / gyro support
```

before important runs.

This type of inspection is often faster and more effective than attempting to compensate for a shifted component through software.

---

# 10.23 Serviceability

A competition robot needs to be adjustable without requiring a complete rebuild.

Piolín's supporting structure should therefore allow access to:

```text
EV3

battery

motor connections

sensor connections

S1 device

Color Sensor

steering system
```

for inspection and maintenance.

Serviceability is an engineering trade-off.

A completely enclosed structure might protect components well, but can make:

```text
charging

port inspection

sensor replacement

mechanical adjustment
```

more difficult.

The current design prioritizes reasonable access to the components that are most likely to be checked between tests.

---

# 10.24 Modularity

Piolín uses one common vehicle platform for both competition challenges.

The permanent mechanical systems are:

```text
chassis

rear drivetrain

front steering

Motor A

Motor B

S2 Left Ultrasonic

S3 Right Ultrasonic

S4 Color Sensor
```

The challenge-specific sensor is:

```text
S1
```

This reduces the amount of mechanical reconfiguration necessary between Open and Obstacles.

The robot remains fundamentally the same vehicle.

---

# 10.25 Why One Common Chassis Is Preferable

Building separate vehicles for each challenge could allow greater specialization.

However, it would also require maintaining:

```text
two drivetrains

two steering systems

two chassis calibrations

two wiring systems

two mechanical baselines
```

Using one common platform allows mechanical improvements to benefit both rounds.

For example:

```text
better steering alignment
```

helps both Open and Obstacles.

```text
lower drivetrain friction
```

also helps both rounds.

```text
stronger chassis rigidity
```

improves all sensor calibrations.

This makes the common platform more efficient to develop.

---

# 10.26 Weight and Mass Distribution

Every supporting component adds mass.

Structural design therefore involves a trade-off between:

```text
rigidity
```

and:

```text
unnecessary weight
```

More beams and reinforcement can improve stiffness, but additional mass also increases the work required from Motor A.

Similarly, component placement affects weight distribution.

The EV3 and battery are among the larger concentrated masses in the vehicle.

The final current V4 mass should be reweighed before being published as an official specification.

No previous mass value should automatically be reused.

---

# 10.27 Dimensions

The current robot's final competition dimensions should also be physically remeasured.

Values that should be verified include:

```text
overall length

overall width

overall height

wheelbase

front track width

rear track width

ground clearance
```

Earlier Piolín measurements can remain in development history, but they should not be presented as final V4 specifications unless confirmed on the current physical robot.

The documentation should prefer:

```text
unknown pending measurement
```

over:

```text
precise but outdated number
```

---

# 10.28 Why Exact Measurements Matter

Physical dimensions affect more than appearance.

For example:

```text
wheelbase
→ steering geometry

track width
→ Ackermann relationship

sensor offset
→ measurement interpretation

camera height
→ image geometry

robot width
→ obstacle clearance
```

Therefore final dimensions should be measured specifically for the current assembled configuration.

These values can later support more detailed calculations in:

```text
mobility documentation

steering documentation

vision calibration

reproducibility
```

---

# 10.29 Components Intentionally Not Included

The current competition robot does not include:

```text
Arduino Nano

HuskyLens

permanent front Ultrasonic Sensor

Raspberry Pi

Arduino Mega

external motor driver

external competition battery

dedicated buck converter
```

These should not appear in current reconstruction instructions.

Some of them remain relevant to Piolín's engineering history and are documented separately under `docs/legacy/`.

---

# 10.30 Historical Supporting Hardware

Earlier prototypes used additional supporting hardware because the sensor architecture was different.

For example, the HuskyLens stage required:

```text
HuskyLens

Arduino Nano

USB communication

additional wiring
```

Removing that system simplified not only software and communication but also the physical robot.

Fewer supporting electronics meant fewer:

```text
mounts

cables

connections

power dependencies
```

This is an example of how one systems-level decision can simplify several engineering layers simultaneously.

---

# 10.31 Reproducibility

Another team reproducing Piolín should understand that the supporting structure must preserve the relationships between the main components.

The most important requirements are not exact cosmetic duplication.

They are:

```text
rigid central chassis

Motor A securely connected to rear drivetrain

Motor B securely connected to steering linkage

S2 mounted on LEFT side

S3 mounted on RIGHT side

S4 facing downward toward floor

S1 device mounted according to active round

wheels moving freely

cables clear of moving mechanisms
```

These relationships define the functional structure of the robot.

---

# 10.32 Mechanical Pre-Run Inspection

A practical pre-run mechanical check can be:

```text
1. Check chassis for loose connections.

2. Check EV3 mounting.

3. Check Motor A mounting.

4. Check Motor B mounting.

5. Rotate rear wheels manually.

6. Verify steering moves freely.

7. Verify S2 mount is secure.

8. Verify S3 mount is secure.

9. Verify Color Sensor and casing are secure.

10. Verify current S1 sensor is secure.

11. Check wheel clearance.

12. Check cable clearance.

13. Verify no component contacts the ground unexpectedly.

14. Begin sensor verification.
```

This procedure isolates physical issues before navigation tuning begins.

---

# 10.33 Mechanical Failure vs. Software Failure

A recurring systems lesson is:

```text
unexpected vehicle behavior
```

does not automatically mean:

```text
software error
```

For example:

| Symptom | Possible Mechanical Cause |
| :--- | :--- |
| Robot curves during straight driving | Steering center shifted |
| Left/right behavior differs | Linkage asymmetry or friction |
| Motor A seems weak | Drivetrain resistance |
| Motor B responds slowly | Steering binding |
| Ultrasonic readings changed | Sensor mount shifted |
| Pixy coordinates changed | Camera mount shifted |
| Color detection became inconsistent | Sensor/casing position changed |

The mechanical system should therefore be inspected before control parameters are changed.

---

# 10.34 Current Supporting-Component Responsibility Matrix

| Supporting Component | Main Responsibility |
| :--- | :--- |
| LEGO Technic chassis | Holds complete vehicle geometry |
| Beams and connectors | Provide structural support |
| Pins and axles | Form joints and rotational transmission |
| Rear wheel assemblies | Transfer propulsion to track |
| Front wheel assemblies | Produce steered vehicle trajectory |
| Motor A mount | Stabilizes propulsion actuator |
| Motor B mount | Stabilizes steering actuator |
| Ultrasonic mounts | Preserve lateral sensing geometry |
| Color Sensor mount | Preserves floor-sensing geometry |
| Color Sensor casing | Reduces ambient-light influence |
| S1 mounting structure | Supports Gyro or Pixy2.1 |
| EV3 cables | Connect LEGO motors and sensors |
| Pixy connection | Integrates obstacle vision with EV3 |

Each part supports another subsystem rather than functioning as an independent navigation device.

---

# 10.35 Values Intentionally Not Claimed as Final

The following should only be published after measurement on the current V4 robot:

```text
final robot mass

overall length

overall width

overall height

wheelbase

front track width

rear track width

front wheel diameter

rear wheel diameter

ground clearance

Color Sensor height

ultrasonic sensor height

sensor offsets

Pixy mounting height

Pixy mounting angle
```

The repository should not reuse stale physical dimensions simply because older versions contained measured values.

Current hardware must be measured directly.

---

# 10.36 Final Structural Architecture

Piolín's supporting mechanical system can be summarized as:

```text
                   LEGO TECHNIC CHASSIS
                           │
       ┌───────────────────┼───────────────────┐
       │                   │                   │
       ▼                   ▼                   ▼
   PROPULSION          STEERING            SENSING
       │                   │                   │
   Motor A             Motor B          S2 / S3 / S4
       │                   │                   │
 rear drivetrain       Ackermann          fixed mounts
       │                   │
       ▼                   ▼
 rear wheels          front wheels

                           +
                           │
                           ▼
                  ROUND-SPECIFIC S1
                    Gyro / Pixy2.1
```

The chassis establishes the physical relationships that allow all these systems to work together.

---

# 10.37 Final Engineering Assessment

Piolín's supporting components demonstrate that autonomous-vehicle performance depends on more than sensors and software.

A sensor must be held in the correct position.

A motor must be connected to a stable mechanism.

A wheel must rotate freely.

A cable must remain clear of moving parts.

A controller must remain securely mounted.

The complete relationship is:

```text
STRUCTURE
    ↓
COMPONENT POSITION
    ↓
MEASUREMENT / ACTUATION
    ↓
SOFTWARE INTERPRETATION
    ↓
VEHICLE BEHAVIOR
```

This is why Piolín's LEGO Technic chassis and supporting components are treated as part of the engineering system rather than as passive construction material.

The final design principle is:

> **Every supporting component should preserve the geometry, alignment, and accessibility required by the subsystem it supports without introducing unnecessary mass or complexity.**

The result is one common mechanical platform capable of supporting both competition configurations while keeping the propulsion, steering, sensing, and electrical architectures consistent and reproducible.

---

<div align="center">

### [← Back to PiolínTech Main README](../../README.md)

</div>

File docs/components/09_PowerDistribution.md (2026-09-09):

# 9. Power Distribution and Electrical Integration

<div align="center">

Piolín wiring in the Open Challenge configuration

<br>

<sub><b>Figure 9.1.</b> Current Piolín wiring in the Open Challenge configuration, where S1 is assigned to the EV3 Gyro Sensor.</sub>

</div>

Piolín uses a deliberately simple electrical architecture centered around the **LEGO Mindstorms EV3 Intelligent Brick** and its **LEGO EV3 Rechargeable DC Battery 45501**.

The EV3 acts as both:

```text
main controller
```

and:

```text
central electrical interface
```

for the current competition vehicle.

The current architecture avoids unnecessary external power electronics, secondary motor controllers, external vehicle batteries, or additional microcontrollers.

Instead, Piolín uses one common EV3 platform whose S1 device changes according to the competition round.

```text
OPEN
S1 = EV3 Gyro Sensor

OBSTACLES
S1 = Pixy2.1
```

The rest of the principal electrical architecture remains unchanged.

---

## 9.1 Electrical Architecture Overview

The current common platform contains:

```text
EV3 Rechargeable Battery 45501
            ↓
      EV3 Intelligent Brick
            │
    ┌───────┼───────┐
    │       │       │
    ▼       ▼       ▼
 MOTORS   SENSORS   CONTROL
```

The permanent motor assignments are:

```text
A
→ EV3 Large Motor
→ rear propulsion

B
→ EV3 Medium Motor
→ front steering
```

The permanent sensor assignments are:

```text
S2
→ LEFT Ultrasonic Sensor

S3
→ RIGHT Ultrasonic Sensor

S4
→ Color Sensor
```

S1 is modular:

```text
S1
├── Open      → Gyro Sensor
└── Obstacles → Pixy2.1
```

This gives Piolín one common electrical base with minimal reconfiguration between competition rounds.

---

# 9.2 Primary Power Source

Piolín's primary power source is:

```text
LEGO Mindstorms EV3 Rechargeable DC Battery
Part 45501
```

<div align="center">

LEGO Mindstorms EV3 Rechargeable DC Battery 45501 used by Piolín

<br>

<sub><b>Figure 9.2.</b> EV3 Rechargeable DC Battery 45501 used as the primary power source for Piolín's current competition platform.</sub>

</div>

The battery is integrated directly into the EV3 Brick.

This simplifies the vehicle because the primary LEGO electronics are already designed around the same controller ecosystem.

The current robot does not require:

```text
external propulsion battery

separate steering battery

separate camera battery

external motor driver

custom power distribution board
```

for its competition architecture.

---

# 9.3 Why Power Is Centralized Through the EV3

Most of Piolín's active components are LEGO Mindstorms EV3 hardware.

These include:

```text
Large Motor

Medium Motor

two Ultrasonic Sensors

Color Sensor

Gyro Sensor during Open
```

Keeping these components on their native EV3 interfaces eliminates the need to build additional conversion electronics for the main vehicle systems.

The electrical philosophy is therefore:

```text
native EV3 component
→ use native EV3 interface
```

whenever practical.

This improves:

```text
simplicity

fault isolation

cable management

competition preparation

reproducibility
```

---

# 9.4 Power Path vs. Signal Path

Power and communication are related but should not be treated as the same concept.

A useful distinction is:

```text
POWER PATH
→ provides electrical energy

SIGNAL PATH
→ transfers information or control commands
```

For example, Motor A needs electrical power to operate, but it also receives control commands from the EV3.

Similarly, a sensor requires power to operate while also returning measurements to the controller.

The current documentation therefore distinguishes:

```text
component is powered
```

from:

```text
component communicates with EV3
```

even when both functions occur through the same physical connection.

---

# 9.5 Motor Power and Control

Piolín uses two EV3 motor outputs.

### Port A

```text
EV3
 ↓
PORT A
 ↓
Large Motor
 ↓
Rear propulsion
```

### Port B

```text
EV3
 ↓
PORT B
 ↓
Medium Motor
 ↓
Ackermann steering
```

The EV3 provides both the electrical interface and the software control path for these motors.

The current architecture does not use an external motor driver between the EV3 and either actuator.

This allows:

```text
navigation decision
      ↓
EV3 motor command
      ↓
motor response
```

without another controller in the chain.

---

# 9.6 Motor Electrical Demand and Mechanical Load

Electrical demand and mechanical load are connected.

For Motor A:

```text
greater drivetrain resistance
→ greater mechanical effort
```

Potential causes include:

```text
axle friction

wheel rubbing

drivetrain misalignment

strong steering resistance
```

For Motor B:

```text
greater steering resistance
→ greater actuator effort
```

Potential causes include:

```text
tight pivots

linkage binding

wheel friction

mechanical misalignment
```

Therefore a motor that appears to be experiencing a power problem may actually be operating against unnecessary mechanical resistance.

The electrical system should not be used to compensate for a mechanically inefficient subsystem.

---

# 9.7 Permanent Sensor Power Architecture

Three sensors remain connected in both rounds:

```text
S2 = LEFT Ultrasonic

S3 = RIGHT Ultrasonic

S4 = Color Sensor
```

These devices form Piolín's permanent sensing layer.

Conceptually:

```text
              EV3
               │
      ┌────────┼────────┐
      │        │        │
      ▼        ▼        ▼
     S2       S3       S4
      │        │        │
      ▼        ▼        ▼
 LEFT US   RIGHT US   COLOR
```

This part of the wiring does not need to be changed when switching between Open and Obstacles.

Keeping the permanent sensors electrically unchanged reduces the possibility of introducing wiring errors between rounds.

---

# 9.8 Modular S1 Electrical Architecture

S1 is the only current sensor port intentionally changed between competition configurations.

```text
                 S1
                 │
         ┌───────┴───────┐
         │               │
         ▼               ▼
       OPEN          OBSTACLES
         │               │
         ▼               ▼
       GYRO            PIXY2.1
```

This design was selected because the two challenges require different information.

During Open:

```text
rotation information
```

is valuable.

During Obstacles:

```text
visual identity
+
visual position
```

is essential.

Using S1 as a modular port avoids adding a secondary controller solely to keep both devices connected simultaneously.

---

# 9.9 Open Challenge Electrical Configuration

The complete current Open configuration is:

```text
                EV3 BATTERY 45501
                       │
                       ▼
                     EV3
                       │
       ┌───────────────┼───────────────┐
       │               │               │
       ▼               ▼               ▼
    MOTORS           SENSORS         CONTROL
       │               │
   ┌───┴───┐      ┌────┼────┬────┐
   │       │      │    │    │    │
   ▼       ▼      ▼    ▼    ▼    ▼
   A       B      S1   S2   S3   S4
   │       │      │    │    │    │
   ▼       ▼      ▼    ▼    ▼    ▼
 Large   Medium  Gyro Left Right Color
 Motor   Motor        US    US  Sensor
```

The corresponding assignments are:

| Port | Open Component |
| :---: | :--- |
| A | EV3 Large Motor — propulsion |
| B | EV3 Medium Motor — steering |
| S1 | EV3 Gyro Sensor |
| S2 | Left Ultrasonic Sensor |
| S3 | Right Ultrasonic Sensor |
| S4 | Color Sensor |

No Pixy2.1 is installed in this configuration.

No Arduino Nano is required.

No HuskyLens is required.

No permanent front ultrasonic sensor is used.

---

# 9.10 Why the Open Wiring Is Simple

The Open Challenge configuration is almost completely LEGO-native.

Its active electrical devices are:

```text
EV3 Brick

EV3 Battery

EV3 Large Motor

EV3 Medium Motor

EV3 Gyro Sensor

2 × EV3 Ultrasonic Sensors

EV3 Color Sensor
```

This creates a short electrical and control path.

For example:

```text
Gyro
 ↓
EV3
 ↓
Motor B
```

The heading measurement does not pass through an additional processor.

Likewise:

```text
Ultrasonic
 ↓
EV3
 ↓
navigation
```

This reduces the number of interfaces that must be checked when debugging the Open Challenge.

---

# 9.11 Obstacle Challenge Electrical Configuration

The Obstacle Challenge uses the same EV3, battery, motors, ultrasonic sensors, and Color Sensor.

Only S1 changes.

<div align="center">

Piolín wiring in the Obstacle Challenge configuration

<br>

<sub><b>Figure 9.3.</b> Current Piolín wiring in the Obstacle Challenge configuration, where Pixy2.1 replaces the Gyro Sensor on S1.</sub>

</div>

The configuration becomes:

```text
                EV3 BATTERY 45501
                       │
                       ▼
                     EV3
                       │
       ┌───────────────┼───────────────┐
       │               │               │
       ▼               ▼               ▼
    MOTORS           SENSORS         CONTROL
       │               │
   ┌───┴───┐      ┌────┼────┬────┐
   │       │      │    │    │    │
   ▼       ▼      ▼    ▼    ▼    ▼
   A       B      S1   S2   S3   S4
   │       │      │    │    │    │
   ▼       ▼      ▼    ▼    ▼    ▼
 Large   Medium Pixy  Left Right Color
 Motor   Motor   2.1   US    US  Sensor
```

The assignments are:

| Port | Obstacle Component |
| :---: | :--- |
| A | EV3 Large Motor — propulsion |
| B | EV3 Medium Motor — steering |
| S1 | Pixy2.1 |
| S2 | Left Ultrasonic Sensor |
| S3 | Right Ultrasonic Sensor |
| S4 | Color Sensor |

The Gyro Sensor is not installed during this round.

---

# 9.12 Pixy2.1 Electrical Integration

Pixy2.1 is the only major active current sensing component outside the LEGO Mindstorms EV3 ecosystem.

<div align="center">

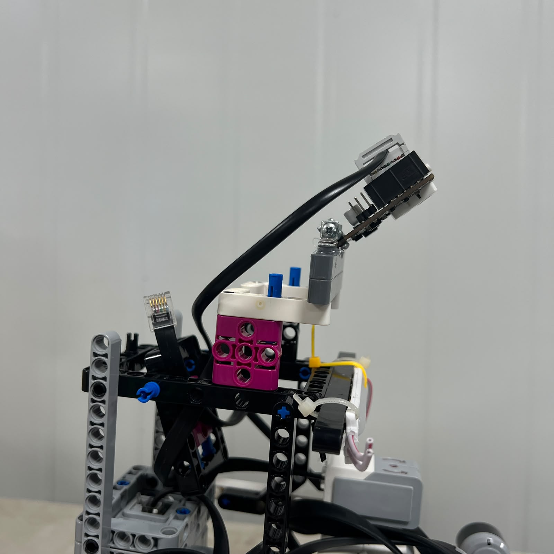
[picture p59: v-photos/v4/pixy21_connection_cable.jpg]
Connection cable used between Pixy2.1 and Piolín's EV3


<br>

<sub><b>Figure 9.4.</b> Current connection used to integrate Pixy2.1 into the EV3-based Obstacle Challenge architecture.</sub>

</div>

The current system uses:

```text
Pixy2.1
   ↓
S1 interface
   ↓
EV3
```

for the Obstacle Challenge.

The current integration provides the communication path used by the EV3 to obtain Pixy block information and supports the camera through the installed S1 connection.

The exact connector pinout and electrical details should be documented only from the actual installed interface or authoritative hardware documentation.

This repository therefore does **not** guess:

```text
individual pin voltage

custom pin mapping

unverified current draw

unverified regulator topology
```

from appearance alone.

---

# 9.13 Pixy Signal Path

During Obstacles, the software obtains visual information through the Pixy interface.

Conceptually:

```text
PILLAR
   ↓
PIXY2.1
   ↓
S1 COMMUNICATION
   ↓
EV3 SOFTWARE
   ↓
TARGET INTERPRETATION
   ↓
MOTOR COMMAND
```

The current obstacle software path uses:

```text
ev3dev2
+
SMBus / I2C
```

for Pixy communication.

This communication architecture belongs to the same EV3 that controls Motor A and Motor B.

There is no second main navigation processor.

---

# 9.14 Power and Data for Pixy Should Not Be Confused

The camera must both:

```text
operate electrically
```

and:

```text
communicate visual information
```

with the EV3.

These functions are related but conceptually separate.

```text
Pixy operating power
        +
Pixy data communication
        ↓
usable vision system
```

When debugging Pixy, the team should therefore distinguish between:

```text
camera does not power correctly
```

and:

```text
camera powers but EV3 receives no valid data
```

because those indicate different failure layers.

---

# 9.15 Why the Arduino Nano Is No Longer Required

Piolín's historical HuskyLens architecture used:

```text
HuskyLens
    ↓ I2C
Arduino Nano
    ↓ USB Serial
EV3
```

The Arduino Nano acted as an interface bridge.

This added:

```text
another electronic board

another communication protocol

another software layer

additional wiring

another debugging stage
```

The current Pixy architecture is shorter:

```text
Pixy2.1
   ↓
EV3
```

The Nano is therefore not part of the current power or wiring architecture.

It remains relevant only in Piolín's legacy engineering history.

---

# 9.16 Why the HuskyLens Is No Longer Powered

The current obstacle robot does not contain HuskyLens.

Therefore the present competition wiring does not need to provide power, communication, or physical mounting for:

```text
HuskyLens

Arduino Nano
```

This distinction is important for reproducibility.

A team reconstructing current Piolín should not reproduce electrical subsystems that belonged only to earlier experiments.

---

# 9.17 No Permanent Front Ultrasonic

Earlier robot configurations also used or explored a frontal ultrasonic sensor.

The current architecture does not.

The final sensor port allocation is:

```text
S1
→ round-specific sensor

S2
→ Left Ultrasonic

S3
→ Right Ultrasonic

S4
→ Color
```

Therefore no additional front ultrasonic connection should appear in the current wiring.

This keeps the electrical documentation consistent with the actual competition configuration.

---

# 9.18 No External Motor Driver

The current LEGO EV3 motors are connected directly through EV3 Motor Ports A and B.

Piolín does not currently require an external motor driver.

The actuation path is:

```text
EV3
 ↓
motor port
 ↓
EV3 motor
```

rather than:

```text
EV3
 ↓
external controller
 ↓
motor driver
 ↓
motor
```

This simplifies:

```text
power distribution

software control

fault diagnosis

reproduction
```

---

# 9.19 No External Competition Battery

The current Piolín platform does not use an additional battery for:

```text
propulsion

steering

vision
```

The primary vehicle energy source remains the EV3 Rechargeable Battery 45501.

This means another team reproducing Piolín does not need to design:

```text
multiple battery rails

battery isolation

multiple charging systems

multiple power switches
```

for the current architecture.

---

# 9.20 No Current External Buck Converter

A dedicated external buck converter is not part of the current final architecture.

This is important because older experimental electronic systems could have required more custom power management.

The final architecture instead moved toward:

```text
fewer external electronics
```

which reduced:

```text
power-conversion requirements

wiring complexity

electronic failure points
```

The repository should therefore not include a buck converter in the current Bill of Materials unless the physical competition robot later changes.

---

# 9.21 Why Electrical Simplification Matters

Every additional electronic component creates dependencies.

For example:

```text
additional processor
→ requires power
→ requires communication
→ requires initialization
→ requires software
→ creates another failure point
```

A systems-engineering question should therefore be:

> Does this component provide information or capability that justifies the complexity it introduces?

This principle directly influenced Piolín's movement from the historical HuskyLens/Nano system toward the current modular EV3 architecture.

---

# 9.22 Cable Routing

Electrical design also interacts with mechanical design.

Cables must remain clear of:

```text
steering linkage

front wheels

rear drivetrain

moving axles
```

A cable that is electrically correct can still create a mechanical failure if it interferes with a moving subsystem.

This is especially important around Motor B.

The steering mechanism moves through a significant range, so cable clearance should be checked at:

```text
left steering

center

right steering
```

rather than inspecting wiring only while the wheels are centered.

---

# 9.23 Why Wiring Must Be Mechanically Secured

Competition movement includes:

```text
acceleration

cornering

reverse movement

wall corrections

obstacle avoidance
```

A loose connector or cable can move during these maneuvers.

The result may appear as an intermittent software failure:

```text
sensor works
→ sensor disconnects
→ sensor works again
```

even though the code has not changed.

Wiring therefore needs:

```text
secure connection

reasonable strain relief

clear routing

mechanical clearance
```

in addition to correct electrical assignment.

---

# 9.24 Electrical Faults Can Look Like Software Faults

Suppose a sensor stops returning useful information.

The visible result could be:

```text
robot drives incorrectly
```

but the cause might be:

```text
software error

wrong port

loose connector

failed initialization

communication issue
```

A useful diagnostic sequence is:

```text
PHYSICAL CONNECTION
        ↓
PORT ASSIGNMENT
        ↓
DEVICE INITIALIZATION
        ↓
RAW DATA
        ↓
PROCESSED DATA
        ↓
NAVIGATION
```

This prevents the navigation controller from being modified unnecessarily when the actual problem exists at the electrical interface.

---

# 9.25 Open Pre-Run Electrical Check

Before an Open Challenge test:

```text
1. Battery installed and sufficiently charged.

2. EV3 powers on correctly.

3. Motor A connected to A.

4. Motor B connected to B.

5. Gyro installed on S1.

6. LEFT Ultrasonic installed on S2.

7. RIGHT Ultrasonic installed on S3.

8. Color Sensor installed on S4.

9. No Pixy installed.

10. No cable interferes with steering or drivetrain.
```

Then verify sensor response before full navigation begins.

---

# 9.26 Obstacle Pre-Run Electrical Check

Before an Obstacle Challenge test:

```text
1. Battery installed and sufficiently charged.

2. EV3 powers on correctly.

3. Motor A connected to A.

4. Motor B connected to B.

5. Pixy2.1 installed on S1.

6. LEFT Ultrasonic installed on S2.

7. RIGHT Ultrasonic installed on S3.

8. Color Sensor installed on S4.

9. Gyro removed.

10. Pixy communication verified.

11. No cable interferes with steering or drivetrain.
```

This sequence prevents the most basic configuration errors from being mistaken for autonomous-navigation problems.

---

# 9.27 Round Change Procedure

Switching Piolín between the two current competition configurations should require only a limited electrical change.

### Open → Obstacles

```text
power down EV3
      ↓
remove Gyro from S1
      ↓
install Pixy2.1 S1 connection
      ↓
verify Pixy mount
      ↓
start obstacle software
```

### Obstacles → Open

```text
power down EV3
      ↓
remove Pixy2.1 from S1
      ↓
install Gyro on S1
      ↓
verify Gyro orientation
      ↓
start Open software
```

S2, S3, S4, Motor A, and Motor B remain unchanged.

This minimizes reconfiguration risk.

---

# 9.28 Why the EV3 Should Be Powered Down During Reconfiguration

Changing the active S1 device is a hardware reconfiguration.

A safe and reproducible procedure is to make the physical change with the EV3 powered down.

This ensures that:

```text
device change
```

and:

```text
software initialization
```

occur in a clearly defined sequence.

Once the correct device is installed, the appropriate round software can initialize the expected hardware.

This also reduces ambiguity during debugging.

---

# 9.29 Software Must Match the Electrical Configuration

Hardware and software must agree.

The Open program expects:

```text
S1 = Gyro
```

while the Obstacle program expects:

```text
S1 = Pixy2.1
```

Running the wrong software with the wrong hardware can produce:

```text
initialization failure

invalid sensor values

missing device errors

unexpected behavior
```

Therefore the round selection is not only a physical wiring decision.

It is a combined:

```text
HARDWARE CONFIGURATION
+
SOFTWARE CONFIGURATION
```

decision.

---

# 9.30 Current Electrical Reproducibility Map

A team reconstructing Piolín should be able to reproduce the electrical architecture from the following assignments.

### Common

```text
Battery
→ EV3 Rechargeable Battery 45501

A
→ EV3 Large Motor

B
→ EV3 Medium Motor

S2
→ LEFT EV3 Ultrasonic Sensor

S3
→ RIGHT EV3 Ultrasonic Sensor

S4
→ EV3 Color Sensor
```

### Open

```text
S1
→ EV3 Gyro Sensor
```

### Obstacles

```text
S1
→ Pixy2.1
```

No current reconstruction requires:

```text
Arduino Nano

HuskyLens

front ultrasonic

external motor driver

external battery

buck converter
```

---

# 9.31 Current vs. Legacy Electrical Architecture

| Component / System | Current | Legacy / Removed |
| :--- | :---: | :---: |
| EV3 Brick | Yes | — |
| EV3 Battery 45501 | Yes | — |
| Motor A Large Motor | Yes | — |
| Motor B Medium Motor | Yes | — |
| S2 Left Ultrasonic | Yes | — |
| S3 Right Ultrasonic | Yes | — |
| S4 Color Sensor | Yes | — |
| S1 Gyro in Open | Yes | — |
| S1 Pixy2.1 in Obstacles | Yes | — |
| Gyro in Obstacles | No | Previous concepts only |
| Pixy in Open | No | Previous experiments only |
| Front ultrasonic | No | Earlier prototype |
| HuskyLens | No | Legacy |
| Arduino Nano | No | Legacy |
| Nano-to-EV3 USB bridge | No | Legacy |
| External motor driver | No | Not required |
| External vehicle battery | No | Not current |
| External buck converter | No | Not current |

This table is intended to prevent historical wiring from being mistaken for current competition architecture.

---

# 9.32 Why Current Photos Are Important

The actual wiring photographs provide stronger reconstruction evidence than a purely conceptual electrical illustration.

They show:

```text
real installed components

real cable routing

real sensor configuration

real controller placement
```

For this reason, the current Open and Obstacle wiring photographs are treated as the primary visual electrical references.

Conceptual diagrams should only be added later if they explain something that cannot be understood from the real hardware or port tables.

---

# 9.33 Values Intentionally Not Claimed as Final

The current documentation does not invent electrical measurements that have not been recorded.

The following should only be added with real measurement or authoritative device documentation:

```text
total current draw

Motor A current

Motor B current

Pixy current draw

individual sensor current

measured battery voltage during operation

measured voltage drop

power consumption per round

measured runtime under competition load

measured electrical efficiency
```

No power-consumption chart should be created without actual measurements.

Likewise, the Pixy connector should not be assigned a detailed custom pinout unless the installed cable/interface is physically verified or documented from an authoritative source.

---
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

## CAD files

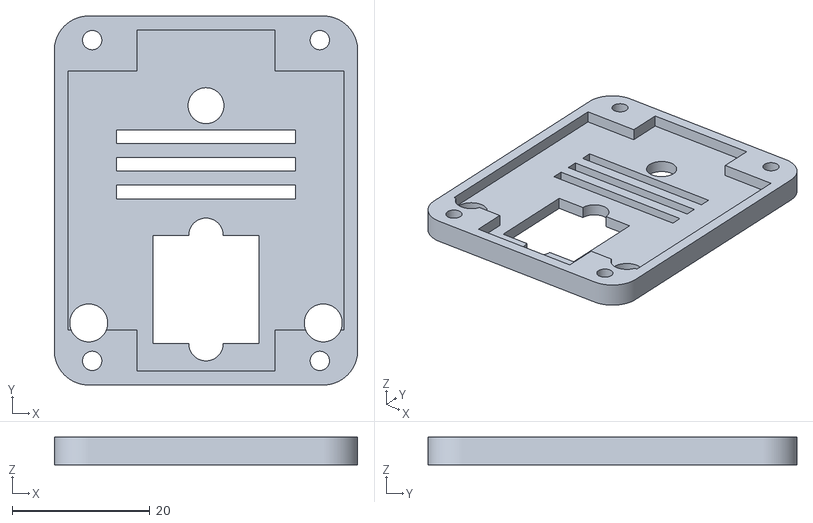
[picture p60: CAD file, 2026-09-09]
models/3dprint/PIXY_Case2.stl
44.0 x 53.5 x 4.00

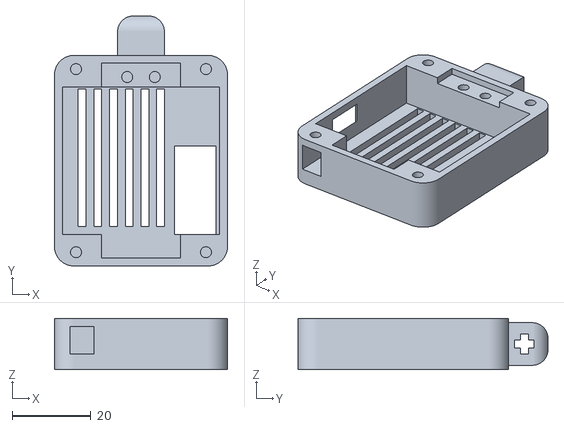
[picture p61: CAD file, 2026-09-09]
models/3dprint/PIXY_Case1.stl
44.0 x 63.5 x 13.0

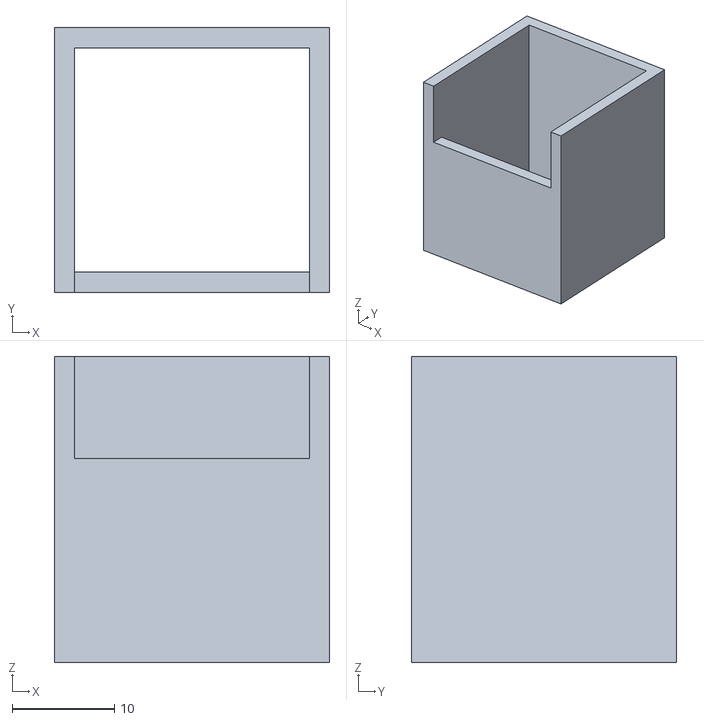
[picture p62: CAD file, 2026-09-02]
models/3dprint/ColorSensorCasing.stl
27.0 x 26.0 x 30.0

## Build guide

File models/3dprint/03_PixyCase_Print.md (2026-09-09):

# Pixy2.1 Case — 3D Printing and Installation

This document describes the manufacturing, assembly, installation, and verification process for Piolín's custom **Pixy2.1 camera casing**.

The current casing is composed of two 3D-printed files:

```text
PIXY_Case1.stl
PIXY_Case2.stl
```

Together, these parts form the physical casing used around the Pixy2.1 camera during Piolín's **Obstacle Challenge configuration**.

The casing is not treated as a decorative component.

It is part of the camera installation because its geometry can influence:

```text
camera position

camera orientation

field of view

mechanical stability

amount of stray light reaching the camera

repeatability of visual detections
```

For this reason, every change to the casing or camera position must be followed by a vision-system verification.

---

## Component Overview

| Property | Current Implementation |
|---|---|
| Files | `PIXY_Case1.stl` + `PIXY_Case2.stl` |
| Component | Pixy2.1 camera casing |
| Vision sensor | Pixy2.1 |
| EV3 port | S1 during Obstacles |
| Communication | Direct Pixy2.1 connection to EV3 |
| Manufacturing method | FDM 3D printing |
| Printer | Anet ET4X |
| Material | OVERTURE High Speed PLA |
| Filament diameter | 1.75 mm |
| Nozzle temperature | 200 °C |
| Heated bed temperature | 80 °C |
| Print speed setting | 100% |
| Competition use | Obstacle Challenge |
| Status | Current |

During the Open Challenge, S1 is used by the EV3 Gyro Sensor instead.

Therefore:

```text
OPEN
S1 → Gyro
```

and:

```text
OBSTACLES
S1 → Pixy2.1
```

The Gyro Sensor and Pixy2.1 are not installed on S1 simultaneously in the current architecture.

---

# Why the Pixy Case Was Needed

The Pixy2.1 is one of the most important sensors in Piolín's Obstacle Challenge configuration.

It is responsible for identifying:

```text
sig1 → Pink → Parking

sig2 → Red → Pass RIGHT

sig3 → Green → Pass LEFT
```

The camera therefore needs a repeatable physical position.

If its position changes:

```text
CAMERA POSITION CHANGES
          ↓
IMAGE GEOMETRY CHANGES
          ↓
x / y / width / height CHANGE
          ↓
TARGET RELEVANCE CHANGES
          ↓
STEERING DECISIONS MAY CHANGE
```

A custom casing was introduced to provide a more controlled and repeatable camera installation.

The casing also provides physical protection and can partially reduce unwanted stray light depending on its geometry.

It does **not** make the Pixy2.1 immune to lighting variation.

Vision calibration is still required.

---

# Current Pixy2.1 Installation

The Pixy2.1 is mounted toward the front of Piolín during the Obstacle Challenge.

<div align="center">

Front view of Piolín's Pixy2.1 camera

<br>

<sub><b>Figure 1.</b> Front view of the Pixy2.1 used in Piolín's current Obstacle Challenge configuration.</sub>

</div>

The camera casing surrounds and supports the vision sensor while preserving the forward sensing area.

<div align="center">

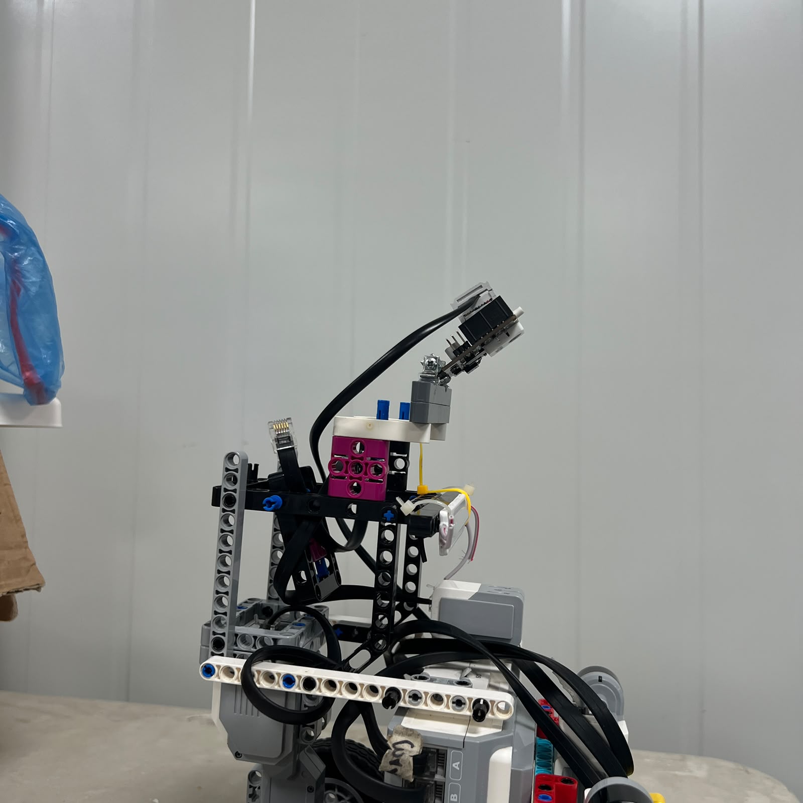
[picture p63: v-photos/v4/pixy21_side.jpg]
Side view of Piolín's Pixy2.1 installation


<br>

<sub><b>Figure 2.</b> Side view of the Pixy2.1 installation.</sub>

</div>

A top view can also be used to inspect the relationship between the camera and the surrounding robot structure.

<div align="center">

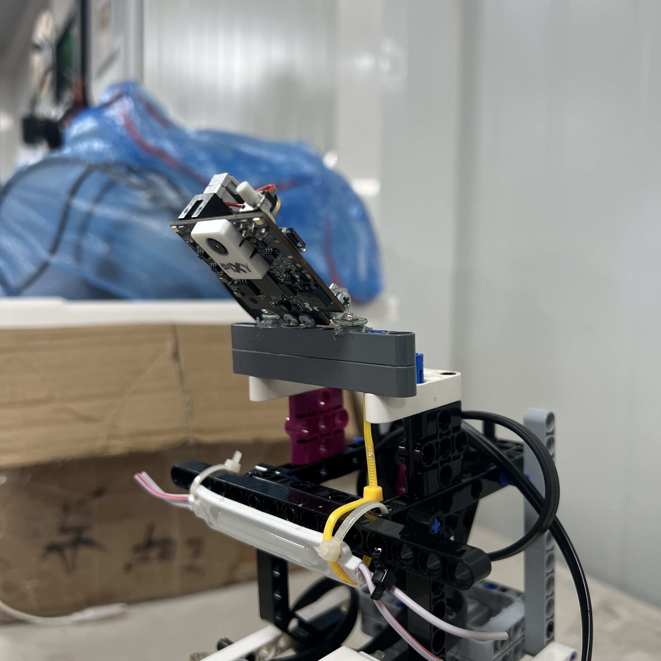
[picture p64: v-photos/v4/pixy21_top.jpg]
Top view of Piolín's Pixy2.1 installation


<br>

<sub><b>Figure 3.</b> Top view of the Pixy2.1 installation and surrounding structure.</sub>

</div>

---

# Manufacturing Parameters

Both casing parts were produced using the same 3D-printing configuration.

| Parameter | Setting |
|---|---:|
| Printer | Anet ET4X |
| Material | OVERTURE High Speed PLA |
| Filament diameter | 1.75 mm |
| Nozzle temperature | 200 °C |
| Heated bed temperature | 80 °C |
| Print speed setting | 100% |

The `100%` speed value refers to the printer speed setting used during manufacturing.

It is not documented as a measured speed in mm/s.

Parameters that were not formally recorded, including exact:

```text
layer height

infill percentage

support configuration

print duration
```

are not presented as measured specifications.

---

# Printing Process

The complete manufacturing sequence is:

```text
PIXY_Case1.stl
       +
PIXY_Case2.stl
       ↓
IMPORT INTO SLICER
       ↓
PREPARE BOTH PARTS
       ↓
SET PRINT PARAMETERS
       ↓
SLICE
       ↓
PREHEAT ANET ET4X
       ↓
BED → 80 °C
NOZZLE → 200 °C
       ↓
PRINT
       ↓
REMOVE PARTS
       ↓
INSPECT
       ↓
TEST PIXY FIT
       ↓
ASSEMBLE CASING
       ↓
INSTALL ON PIOLÍN
       ↓
VERIFY FIELD OF VIEW
       ↓
VERIFY COLOR SIGNATURES
       ↓
VALIDATE ON TRACK
```

Both pieces must work together as one camera-support assembly.

---

# Post-Print Inspection

After printing, both components are inspected before installation.

The checks include:

```text
Are both parts complete?

Is either part visibly deformed?

Does Pixy2.1 fit correctly?

Is the camera lens area unobstructed?

Are the connection points accessible?

Can the cable remain connected?

Does the casing interfere with nearby LEGO structure?

Can the assembly remain mechanically stable?
```

A successful print must satisfy both:

```text
MECHANICAL FIT
```

and:

```text
VISION COMPATIBILITY
```

A casing that physically fits but blocks part of the camera view is not considered a successful design.

---

# Assembly

The two STL files represent parts of the same camera casing:

```text
PIXY_Case1.stl
      +
PIXY_Case2.stl
      ↓
PIXY2.1 CASING ASSEMBLY
```

The camera is placed within the casing so that the vision area remains exposed.

The assembly process must preserve:

```text
camera opening

camera orientation

cable access

mechanical support
```

The exact physical assembly method is determined by the final printed geometry and Piolín's current mounting configuration.

No unrecorded assembly dimensions or fastening specifications are presented as measured values.

---

# Installation on Piolín

After assembly, the casing is mounted on Piolín in the Obstacle Challenge configuration.

The current electrical architecture is:

```text
Pixy2.1
   ↓
S1
   ↓
EV3 Brick
```

<div align="center">

Pixy2.1 connected to Piolín through EV3 S1

<br>

<sub><b>Figure 4.</b> Pixy2.1 connection to EV3 sensor port S1 in the Obstacle Challenge configuration.</sub>

</div>

The current Pixy2.1 architecture uses a direct connection to the EV3.

Earlier HuskyLens and Arduino Nano configurations are legacy development architectures and are not part of this current camera installation.

---

# Installation Verification

Once mounted, the camera installation is checked before software tuning begins.

The verification sequence is:

```text
INSTALL CASING
      ↓
CHECK CAMERA FIT
      ↓
CHECK CAMERA OPENING
      ↓
CHECK CABLE
      ↓
CHECK CAMERA ORIENTATION
      ↓
POWER PIXY2.1
      ↓
VERIFY EV3 COMMUNICATION
      ↓
TEST COLOR SIGNATURES
```

The team checks that the casing does not:

```text
block the camera

cover the lens

interfere with S1 connection

force the camera into an unusable orientation

move excessively during robot motion
```

---

# Effect on Vision Geometry

The casing is part of the complete vision system because Pixy2.1 produces geometric information about detected objects.

Useful block data includes:

```text
signature

x

y

width

height
```

The physical camera installation affects how those values appear.

For example:

```text
CAMERA MOVED UP / DOWN
→ apparent y and size can change
```

```text
CAMERA ROTATED
→ target positions inside image can change
```

```text
CAMERA MOVED SIDEWAYS
→ apparent x can change
```

Therefore:

> **Pixy calibration should always be performed using the same physical camera installation that will be used during competition.**

---

# Red Pillar Verification

The Red obstacle signature is:

```text
sig2
→ RED
→ PASS RIGHT
```

After the casing is installed, Red detection is tested again.

<div align="center">

Pixy2.1 detecting a Red obstacle pillar

<br>

<sub><b>Figure 5.</b> Pixy2.1 Red-pillar detection used to verify the installed camera system.</sub>

</div>

The test verifies that the installed camera can still provide a usable Red block to the perception system.

The camera's image position does not determine the competition passing side.

The rule remains:

```text
RED
→ RIGHT
```

regardless of whether the Red block appears on the left, center, or right side of the image.

---

# Green Pillar Verification

The Green signature is:

```text
sig3
→ GREEN
→ PASS LEFT
```

<div align="center">

Pixy2.1 detecting a Green obstacle pillar

<br>

<sub><b>Figure 6.</b> Pixy2.1 Green-pillar detection used to verify the installed camera system.</sub>

</div>

The fixed navigation rule is:

```text
GREEN
→ LEFT
```

The camera's `x` coordinate may influence the magnitude or geometry of the maneuver, but it does not redefine which side of the pillar Piolín must use.

---

# Pink Parking Verification

The parking signature is:

```text
sig1
→ PINK
→ Parking reference
```

The Pink reference is also tested after installation.

<div align="center">

Pixy2.1 detecting the Pink parking reference

<br>

<sub><b>Figure 7.</b> Pixy2.1 detection of the Pink parking reference after camera installation.</sub>

</div>

The camera must be able to provide useful Pink observations for the parking perception system.

However:

```text
PINK DETECTED
≠
IMMEDIATE PARKING
```

The navigation architecture also requires:

```text
course progression complete
+
Pink confirmation
+
parking eligibility
```

before the parking maneuver begins.

---

# Recalibration After Installation

Installing or modifying the Pixy casing may affect the vision geometry.

For that reason, the correct process is:

```text
PRINT
   ↓
ASSEMBLE
   ↓
INSTALL
   ↓
VERIFY CAMERA POSITION
   ↓
TEST RED
   ↓
TEST GREEN
   ↓
TEST PINK
   ↓
OBSERVE x / y / width / height
   ↓
ADJUST SOFTWARE THRESHOLDS IF REQUIRED
   ↓
TEST WHILE MOVING
```

The previous calibration should not automatically be assumed valid after a significant physical change.

---

# Relationship with Vision Processing

The printed casing supports the physical camera layer.

It does not make navigation decisions.

The complete information path is:

```text
PHYSICAL PILLAR
      ↓
PIXY2.1 + CASING
      ↓
RAW PIXY BLOCKS
      ↓
VALIDATION
      ↓
CANDIDATE SELECTION
      ↓
CONFIRMATION
      ↓
TARGET LOCK
      ↓
NAVIGATION STATE MACHINE
      ↓
OBSTACLE CONTROLLER
      ↓
CONTROL ARBITRATION
      ↓
MOTOR B
```

The detailed Pixy processing architecture is documented in:

[Pixy2.1 Vision Processing Flowchart](../../embed/02_VProcessing.md)

The detailed pillar maneuver is documented in:

[Obstacle Strategy Flowchart](../../embed/05_ObstacleStrategyFC.md)

The overall control hierarchy is documented in:

[Control Arbitration Flowchart](../../embed/04_ControlArbitration.md)

---

# Engineering Iteration

The Pixy casing is part of PiolínTech's sensor-development process.

The architecture evolved through multiple vision approaches before reaching the current direct Pixy2.1 configuration.

The current physical workflow is:

```text
VISION REQUIREMENT
      ↓
CAMERA SELECTION
      ↓
PHYSICAL MOUNTING
      ↓
3D-PRINTED CASING
      ↓
FIT TEST
      ↓
VISION TEST
      ↓
SOFTWARE CALIBRATION
      ↓
TRACK VALIDATION
```

This illustrates the relationship between:

```text
MECHANICAL DESIGN

ELECTRONICS

PERCEPTION

SOFTWARE CONTROL
```

A camera algorithm cannot be calibrated independently from the physical camera installation.

---

# Reproduction Procedure

To reproduce the current Pixy2.1 casing:

### Required files

```text
PIXY_Case1.stl

PIXY_Case2.stl
```

### Printer

```text
Anet ET4X
```

### Material

```text
OVERTURE High Speed PLA
1.75 mm
```

### Printing configuration

```text
Nozzle temperature:
200 °C

Heated bed:
80 °C

Print speed setting:
100%
```

### Post-print procedure

```text
1. Inspect both printed components.

2. Verify that Pixy2.1 fits inside the casing.

3. Confirm that the camera opening remains unobstructed.

4. Confirm that cable access remains available.

5. Assemble the two casing components.

6. Install the Pixy2.1 assembly on Piolín.

7. Connect Pixy2.1 to S1.

8. Verify communication with the EV3.

9. Verify Red / sig2 detection.

10. Verify Green / sig3 detection.

11. Verify Pink / sig1 detection.

12. Inspect x, y, width, and height behavior.

13. Recalibrate perception thresholds if required.

14. Test detection while Piolín is moving.

15. Validate the installation during obstacle maneuvers.
```

---

# Reproduction Checklist

| Check | Expected Result |
|---|---|
| `PIXY_Case1.stl` printed | Complete physical part |
| `PIXY_Case2.stl` printed | Complete physical part |
| Pixy fits casing | Camera can be installed |
| Camera opening clear | Lens/FOV not physically blocked |
| Cable accessible | S1 connection possible |
| Assembly stable | Camera position remains repeatable |
| Pixy powers and communicates | EV3 receives camera information |
| `sig2` detected | Red pillar can be identified |
| `sig3` detected | Green pillar can be identified |
| `sig1` detected | Pink parking reference can be identified |
| Track testing completed | Installation works under robot motion |

---

# System Relationship

The role of the printed casing can be summarized as:

```text
PIXY_Case1.stl
       +
PIXY_Case2.stl
       ↓
PHYSICAL CAMERA CASING
       ↓
REPEATABLE PIXY INSTALLATION
       ↓
MORE CONSISTENT IMAGE GEOMETRY
       ↓
TARGET VALIDATION
       ↓
OBSTACLE / PARKING PERCEPTION
       ↓
AUTONOMOUS CONTROL
```

This is why the casing is considered part of the vision architecture rather than only a mechanical accessory.

---

# Engineering Summary

The Pixy2.1 casing demonstrates how a mechanical component can directly support software reliability.

PiolínTech's complete reasoning chain is:

```text
VISION NEEDS REPEATABLE INPUT
          ↓
CAMERA NEEDS REPEATABLE POSITION
          ↓
CUSTOM CASING IS DESIGNED
          ↓
CASING IS 3D PRINTED
          ↓
PIXY2.1 IS INSTALLED
          ↓
SIGNATURES ARE VERIFIED
          ↓
IMAGE GEOMETRY IS CHECKED
          ↓
SOFTWARE IS RECALIBRATED
          ↓
FULL OBSTACLE TESTING
```

The central design principle is:

> **The Pixy2.1 casing is considered successful only when it provides a stable physical camera installation without obstructing vision, and when Red, Green, and Pink detections remain reliable after the completed assembly is installed on Piolín.**

---

<div align="center">

### [← Back to 3D Printing Process](PrintingProcess.md)

</div>

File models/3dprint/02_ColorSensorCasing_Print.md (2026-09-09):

# Color Sensor Casing — 3D Printing and Installation

This document describes the manufacturing, installation, and verification process for Piolín's custom **EV3 Color Sensor casing**.

The casing is manufactured from:

```text
ColorSensorCasing.stl
```

and is installed around the downward-facing **LEGO EV3 Color Sensor connected to S4**.

Its purpose is not decorative. The component was introduced to create a more controlled physical environment around the sensor and reduce the influence of uncontrolled ambient light on floor readings.

This is particularly important because S4 is used to detect the WRO course's:

```text
BLUE markings

ORANGE markings
```

which contribute to:

```text
initial direction detection

course-event recognition

progress counting

corner context

parking eligibility
```

---

## 1. Component Overview

| Property | Current Implementation |
|---|---|
| File | `ColorSensorCasing.stl` |
| Component | S4 Color Sensor casing |
| Sensor | LEGO EV3 Color Sensor |
| Sensor port | S4 |
| Manufacturing method | FDM 3D printing |
| Printer | Anet ET4X |
| Material | OVERTURE High Speed PLA |
| Filament diameter | 1.75 mm |
| Nozzle temperature | 200 °C |
| Heated bed temperature | 80 °C |
| Print speed setting | 100% |
| Status | Current |

The casing is part of Piolín's current sensing installation.

---

## 2. Why the Casing Was Needed

The EV3 Color Sensor is mounted close to the floor and reads reflected light from the surface below Piolín.

Without some physical isolation, its measurements can be influenced by changes in the surrounding optical environment.

Possible sources of variation include:

```text
room lighting

competition-area lighting

shadows

light entering from the sides

different robot orientations relative to lights
```

The casing creates a more controlled region around the sensor.

The design objective is:

```text
UNCONTROLLED AMBIENT LIGHT
            ↓
     PHYSICAL CASING
            ↓
MORE CONTROLLED SENSOR AREA
            ↓
        S4 READING
            ↓
  FLOOR CLASSIFICATION
```

The casing does not make the Color Sensor completely immune to lighting changes.

For this reason, the sensor is still calibrated and physically tested after installation.

---

## 3. Physical Installation

Piolín's Color Sensor is mounted:

```text
downward-facing
```

with the casing surrounding the sensing area.

<div align="center">

Piolín S4 EV3 Color Sensor installed on the robot

<br>

<sub><b>Figure 1.</b> Piolín's downward-facing EV3 Color Sensor installed on S4.</sub>

</div>

The casing is installed so that it can shield the surrounding sensing region without preventing the sensor from observing the floor.

<div align="center">

Piolín custom 3D-printed Color Sensor casing

<br>

<sub><b>Figure 2.</b> Custom 3D-printed casing used around Piolín's Color Sensor.</sub>

</div>

The bottom view is particularly important because the final installation must leave the sensing path unobstructed.

<div align="center">

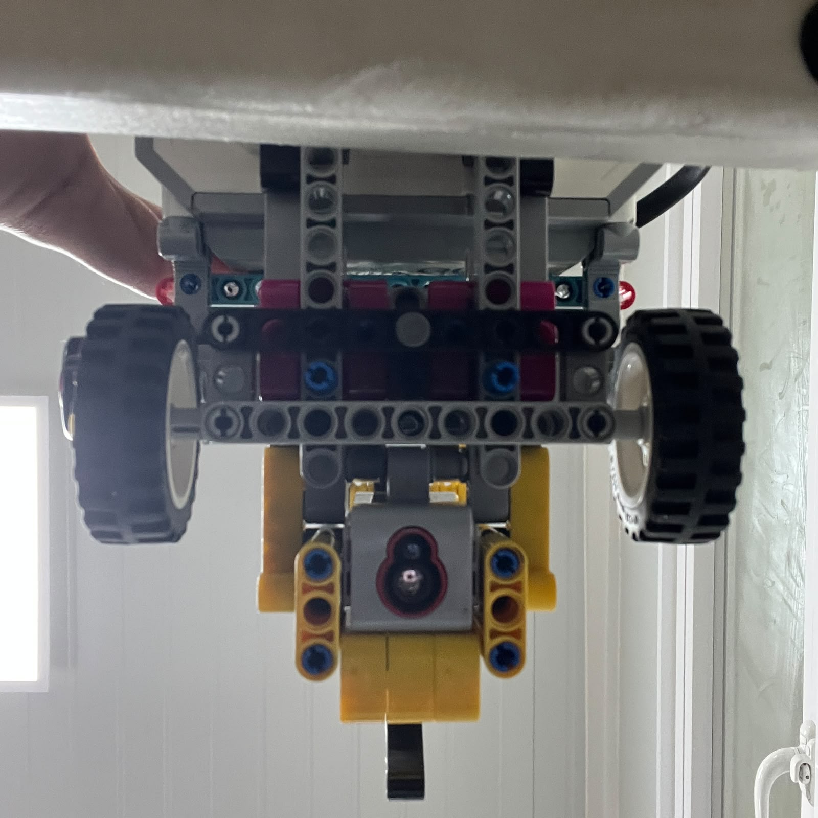
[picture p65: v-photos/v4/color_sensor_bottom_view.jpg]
Bottom view of Piolín Color Sensor and casing


<br>

<sub><b>Figure 3.</b> Bottom view of the Color Sensor installation and surrounding casing.</sub>

</div>

---

# 4. Manufacturing Parameters

The casing was printed using the same manufacturing setup documented for PiolínTech's current 3D-printed components.

| Parameter | Setting |
|---|---:|
| Printer | Anet ET4X |
| Material | OVERTURE High Speed PLA |
| Filament diameter | 1.75 mm |
| Nozzle temperature | 200 °C |
| Heated bed temperature | 80 °C |
| Print speed setting | 100% |

The `100%` value represents the printer's speed setting used during manufacturing. It is not documented as a measured speed in mm/s.

Parameters that were not formally recorded during manufacturing, such as exact:

```text
layer height

infill percentage

support configuration

print duration
```

are not presented here as measured values.

This avoids introducing unverified fabrication specifications into the repository.

---

# 5. Printing Process

The manufacturing sequence for the casing was:

```text
ColorSensorCasing.stl
        ↓
IMPORT INTO SLICER
        ↓
PREPARE MODEL
        ↓
SET PRINT PARAMETERS
        ↓
SLICE
        ↓
PREHEAT ANET ET4X
        ↓
BED → 80 °C
NOZZLE → 200 °C
        ↓
PRINT AT 100% SPEED SETTING
        ↓
REMOVE COMPONENT
        ↓
VISUAL INSPECTION
        ↓
FIT TEST
        ↓
INSTALL ON PIOLÍN
        ↓
VERIFY COLOR SENSOR
```

The printing stage is only one part of the complete process.

A finished print is not accepted until its fit and sensor behavior have also been checked.

---

## 6. Post-Print Inspection

After printing, the casing is inspected before being installed.

The main checks are:

```text
Is the main geometry complete?

Is the component visibly deformed?

Can the Color Sensor fit correctly?

Is the sensing opening unobstructed?

Can the S4 cable remain connected normally?

Does the casing interfere with nearby LEGO structure?
```

A casing that prints successfully but obstructs the sensor is not considered a successful component.

The inspection therefore evaluates:

```text
MANUFACTURING QUALITY
+
ROBOT COMPATIBILITY
+
SENSOR COMPATIBILITY
```

---

# 7. Installation Verification

After the casing is mounted on Piolín, the team checks the complete installation.

The verification sequence is:

```text
INSTALL CASING
      ↓
CHECK PHYSICAL FIT
      ↓
CHECK SENSOR ORIENTATION
      ↓
CHECK FLOOR CLEARANCE
      ↓
CHECK SENSOR OPENING
      ↓
CHECK S4 CABLE
      ↓
POWER ROBOT
      ↓
READ SENSOR
```

The casing should not:

```text
block the Color Sensor

touch the track surface

interfere with the cable

move the sensor into an unusable orientation
```

The objective is to improve the sensor environment without preventing normal sensing.

---

# 8. Blue and Orange Verification

After installation, the sensor must be tested again on the actual floor markings.

The two important course references are:

```text
BLUE
```

and:

```text
ORANGE
```

<div align="center">

Piolín Color Sensor testing a Blue course marking

<br>

<sub><b>Figure 4.</b> Color Sensor verification over a Blue course marking.</sub>

</div>

<div align="center">

Piolín Color Sensor testing an Orange course marking

<br>

<sub><b>Figure 5.</b> Color Sensor verification over an Orange course marking.</sub>

</div>

The testing objective is not simply to confirm that the sensor reports a value.

The team checks whether the readings are sufficiently distinguishable for the software's floor-classification logic.

The process is:

```text
NEUTRAL FLOOR
      ↓
record sensor behavior

BLUE
      ↓
record sensor behavior

ORANGE
      ↓
record sensor behavior
```

Then the software classification can be checked against the real physical installation.

---

# 9. Relationship with Software Calibration

Changing the physical environment around an optical sensor can change the measurements received by the software.

Therefore:

```text
NEW CASING
≠
OLD CALIBRATION AUTOMATICALLY VALID
```

The correct sequence is:

```text
PRINT CASING
      ↓
INSTALL CASING
      ↓
VERIFY SENSOR POSITION
      ↓
READ REAL FLOOR VALUES
      ↓
CHECK BLUE
      ↓
CHECK ORANGE
      ↓
CHECK NEUTRAL FLOOR
      ↓
ADJUST CLASSIFICATION IF REQUIRED
      ↓
TEST WHILE MOVING
```

Piolín's software can use information such as:

```text
reflection

red channel

green channel

blue channel
```

to distinguish course markings.

The physical casing and software classifier therefore form a combined sensing system.

---

# 10. Color Event Processing

The casing supports the sensing layer, but it does not directly control navigation.

The complete architecture is:

```text
PHYSICAL FLOOR
      ↓
3D-PRINTED CASING
      ↓
S4 COLOR SENSOR
      ↓
RGB / REFLECTION READING
      ↓
FLOOR CLASSIFICATION
      ↓
EVENT CONFIRMATION
      ↓
LATCH / DUPLICATE PROTECTION
      ↓
ACCEPTED COURSE EVENT
      ↓
NAVIGATION STATE MACHINE
```

This separation is important.

The casing improves the physical sensing environment.

The software is still responsible for:

```text
classification

confirmation

event counting

duplicate prevention

state interpretation
```

The detailed color-event architecture is documented in:

[Color Event Processing Flowchart](../../embed/06_ColorEventFC.md)

---

# 11. Engineering Iteration

The Color Sensor casing represents a hardware response to a sensing problem.

The development relationship is:

```text
OBSERVE VARIABLE SENSOR BEHAVIOR
              ↓
IDENTIFY LIGHT AS A POSSIBLE FACTOR
              ↓
ADD PHYSICAL SENSOR ISOLATION
              ↓
3D PRINT CASING
              ↓
INSTALL
              ↓
RETEST SENSOR
              ↓
RECALIBRATE SOFTWARE
```

This is important because the solution does not rely only on adding more software filtering.

Instead, PiolínTech addresses the problem at both:

```text
PHYSICAL LEVEL
```

and:

```text
SOFTWARE LEVEL
```

The physical system attempts to make the measurements more repeatable, while software handles classification and event processing.

---

# 12. Reproduction Procedure

To reproduce the current casing:

### Required file

```text
ColorSensorCasing.stl
```

### Printer

```text
Anet ET4X
```

### Material

```text
OVERTURE High Speed PLA
1.75 mm
```

### Printing parameters

```text
Nozzle: 200 °C

Bed: 80 °C

Speed setting: 100%
```

### After printing

```text
1. Inspect the printed geometry.

2. Test-fit the EV3 Color Sensor.

3. Install the casing on Piolín.

4. Verify that the sensing opening remains unobstructed.

5. Verify that the sensor does not contact the floor.

6. Verify the S4 connection.

7. Test neutral floor readings.

8. Test Blue.

9. Test Orange.

10. Recalibrate the software classifier if required.

11. Test color-event detection while Piolín is moving.
```

---

# Engineering Summary

The `ColorSensorCasing.stl` component connects mechanical design directly to autonomous sensing.

```text
3D MODEL
   ↓
FDM PRINT
   ↓
PHYSICAL CASING
   ↓
CONTROLLED SENSOR ENVIRONMENT
   ↓
S4 MEASUREMENTS
   ↓
BLUE / ORANGE CLASSIFICATION
   ↓
COURSE EVENTS
   ↓
NAVIGATION
```

The casing is therefore not simply an accessory around the sensor.

It is part of Piolín's complete:

```text
MECHANICAL
+
OPTICAL
+
SOFTWARE
```

sensing architecture.

The central design principle is:

> **The Color Sensor casing was introduced to make the physical sensing environment more controlled and repeatable. After manufacturing and installation, its effectiveness is verified through real S4 measurements and course-marking tests rather than assumed from the printed geometry alone.**

---

<div align="center">

### [← Back to 3D Printing Process](PrintingProcess.md)

</div>

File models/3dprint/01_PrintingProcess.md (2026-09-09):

# PiolínTech 3D Printing Process

This directory documents the **3D-printed components designed, manufactured, tested, and installed on Piolín** during the development of the WRO Future Engineers 2026 robot.

3D printing was used where the standard LEGO structure did not provide the exact geometry required for a sensor installation.

The current printed components are:

```text
ColorSensorCasing.stl

PIXY_Case1.stl

PIXY_Case2.stl
```

These components support two important sensing systems:

```text
S4 Color Sensor
→ ColorSensorCasing.stl
```

and:

```text
Pixy2.1
→ PIXY_Case1.stl
→ PIXY_Case2.stl
```

---

# Printing Equipment

PiolínTech manufactured the current printed components using an:

**Anet ET4X 3D Printer**

The printer provides sufficient build space for the custom sensor housings used on Piolín.

<div align="center">

Anet ET4X 3D printer used by PiolínTech

<br>

<sub><b>Figure 1.</b> Anet ET4X 3D printer used to manufacture Piolín's custom sensor components.</sub>

</div>

The available build volume for this printer model is:

```text
220 × 220 × 250 mm
```

This was sufficient for the sensor-casing components used on Piolín.

---

# Filament

The material used for the printed components was:

**OVERTURE High Speed PLA**

with:

```text
Filament diameter: 1.75 mm
Spool size:        1 kg
```

<div align="center">

OVERTURE High Speed PLA filament used by PiolínTech

<br>

<sub><b>Figure 2.</b> OVERTURE High Speed PLA filament used to manufacture Piolín's custom 3D-printed components.</sub>

</div>

PLA was used to manufacture the custom sensor-support components installed on the robot.

---

# Printing Parameters

The printing configuration used by PiolínTech was:

| Parameter | Setting |
|---|---:|
| Printer | Anet ET4X |
| Filament | OVERTURE High Speed PLA |
| Filament diameter | 1.75 mm |
| Nozzle temperature | 200 °C |
| Heated bed temperature | 80 °C |
| Print speed setting | 100% |
| Available build volume | 220 × 220 × 250 mm |

The `100%` speed value refers to the **printer speed setting used during manufacturing**, rather than a measured linear printing speed in mm/s.

Parameters that were not formally recorded during the original manufacturing process are not presented as measured specifications in this repository.

---

# Manufacturing Workflow

The general manufacturing process used by PiolínTech was:

```text
3D MODEL
   ↓
EXPORT STL
   ↓
IMPORT INTO SLICER
   ↓
PREPARE MODEL
   ↓
SET PRINT PARAMETERS
   ↓
SLICE
   ↓
TRANSFER PRINT FILE
   ↓
PREHEAT PRINTER
   ↓
PRINT
   ↓
REMOVE PART
   ↓
INSPECT
   ↓
TEST FIT
   ↓
INSTALL ON PIOLÍN
   ↓
RECALIBRATE SENSOR
```

The objective of this process was not only to manufacture the part successfully, but also to ensure that the printed component worked correctly as part of Piolín's complete sensor system.

---

# 1. Prepare the STL

The required model is first selected from the `3dprint/` directory.

Current files:

```text
ColorSensorCasing.stl
PIXY_Case1.stl
PIXY_Case2.stl
```

The STL file is imported into the slicing software before printing.

At this stage, the model is prepared for fabrication on the Anet ET4X.

---

# 2. Prepare the Print

Before beginning the print, the model is positioned and prepared in the slicing software.

The temperature configuration used by PiolínTech was:

```text
NOZZLE
→ 200 °C
```

```text
HEATED BED
→ 80 °C
```

The printer speed setting used during these prints was:

```text
100%
```

The objective of documenting these settings is to make it possible to reproduce the manufacturing process if one of Piolín's printed components must be replaced.

---

# 3. Preheat the Printer

Before extrusion begins, the Anet ET4X is brought to the configured printing temperatures.

```text
BED
→ 80 °C
```

```text
NOZZLE
→ 200 °C
```

Printing begins after the printer reaches the required operating temperatures.

---

# 4. Print the Component

The sliced model is then printed using:

```text
PRINTER
Anet ET4X

FILAMENT
OVERTURE High Speed PLA
1.75 mm

NOZZLE
200 °C

BED
80 °C

PRINT SPEED SETTING
100%
```

During manufacturing, the print is monitored for obvious problems that could affect the final geometry or installation of the component.

Examples include:

```text
major deformation

incomplete sections

poor attachment to the print surface

unexpected movement of the part

geometry that could affect sensor fit
```

---

# 5. Remove and Inspect

After printing is complete, the part is removed from the printer and visually inspected.

The team checks whether the component contains problems that could prevent proper installation.

This includes checking for:

```text
major deformation

incomplete geometry

incorrect fit

blocked sensor openings

cable interference

interference with nearby LEGO structure
```

A component is therefore not considered successful only because the 3D printer completed the job.

It must also function correctly when installed on Piolín.

---

# Fit Testing

Each printed component is physically tested on the robot before being accepted.

The general verification process is:

```text
PRINT
   ↓
FIT ON ROBOT
   ↓
CHECK POSITION
   ↓
CHECK SENSOR
   ↓
CHECK CABLES
   ↓
CHECK CLEARANCE
   ↓
ACCEPT OR MODIFY
```

If the component does not provide the intended result:

```text
MODEL
   ↓
MODIFY
   ↓
REPRINT
   ↓
RETEST
```

This makes 3D printing part of PiolínTech's iterative engineering process rather than only a manufacturing step.

---

# Color Sensor Casing

The file:

```text
ColorSensorCasing.stl
```

is used for the custom casing surrounding Piolín's downward-facing **S4 EV3 Color Sensor**.

The casing was developed to create a more controlled physical environment around the sensor and reduce the influence of uncontrolled external light on floor readings.

This is especially relevant when distinguishing:

```text
Blue course markings

Orange course markings
```

The complete relationship is:

```text
EXTERNAL LIGHT
      ↓
COLOR SENSOR ENVIRONMENT
      ↓
S4 MEASUREMENTS
      ↓
RGB / REFLECTION VALUES
      ↓
COLOR CLASSIFICATION
```

By adding a physical casing around the sensor, PiolínTech can make the sensing environment more repeatable.

However, installing the casing can also change the sensor's actual readings.

Therefore:

```text
PRINT
→ INSTALL
→ TEST S4
→ RECALIBRATE IF REQUIRED
```

Detailed manufacturing and installation documentation is available in:

[Color Sensor Casing Print](ColorSensorCasing_Print.md)

---

# Pixy2.1 Case

The current Pixy2.1 casing is composed of:

```text
PIXY_Case1.stl

PIXY_Case2.stl
```

The printed pieces form part of the physical camera installation used during the **Obstacle Challenge**.

The casing contributes to:

```text
mechanical protection

camera support

repeatable installation

more consistent camera positioning

partial shielding from stray light,
depending on casing geometry
```

Because the casing changes the physical installation of Pixy2.1, it is treated as part of the complete vision system rather than as a purely cosmetic component.

The relationship is:

```text
3D-PRINTED CASE
      ↓
CAMERA POSITION
      ↓
CAMERA FIELD OF VIEW
      ↓
PIXY BLOCK GEOMETRY
      ↓
VISION PROCESSING
      ↓
NAVIGATION DECISION
```

After installation, PiolínTech verifies:

```text
camera opening remains unobstructed

Pixy cable remains unobstructed

camera orientation remains usable

Red pillar detection

Green pillar detection

Pink parking detection
```

Detailed manufacturing and installation documentation is available in:

[Pixy2.1 Case Print](PixyCase_Print.md)

---

# Post-Installation Calibration

A 3D-printed sensor component is not treated independently from the sensor's software calibration.

The complete process is:

```text
PRINT COMPONENT
      ↓
INSTALL
      ↓
VERIFY PHYSICAL FIT
      ↓
TEST SENSOR
      ↓
COLLECT REAL READINGS
      ↓
ADJUST CALIBRATION IF REQUIRED
      ↓
VALIDATE ON PIOLÍN
```

For the Color Sensor casing:

```text
physical casing
      ↓
optical environment changes
      ↓
S4 readings verified
      ↓
Blue / Orange detection retested
```

For the Pixy2.1 casing:

```text
physical camera installation
      ↓
camera geometry / field of view
      ↓
Pixy blocks verified
      ↓
Red / Green / Pink detection retested
```

This relationship between manufacturing and sensing is important because a physically successful print is only useful if the corresponding sensor remains reliable after installation.

---

# Current 3D-Printed Components

| File | System | Function |
|---|---|---|
| `ColorSensorCasing.stl` | S4 Color Sensor | Creates a more controlled physical and optical environment around the floor sensor |
| `PIXY_Case1.stl` | Pixy2.1 | Part of the custom camera casing |
| `PIXY_Case2.stl` | Pixy2.1 | Part of the custom camera casing |

---

# Reproducing the Prints

The currently documented manufacturing configuration is:

```text
3D PRINTER
Anet ET4X
```

```text
FILAMENT
OVERTURE High Speed PLA
Diameter: 1.75 mm
```

```text
NOZZLE TEMPERATURE
200 °C
```

```text
BED TEMPERATURE
80 °C
```

```text
PRINT SPEED SETTING
100%
```

The available STL files are:

```text
ColorSensorCasing.stl

PIXY_Case1.stl

PIXY_Case2.stl
```

After manufacturing:

```text
INSPECT
   ↓
TEST FIT
   ↓
INSTALL
   ↓
VERIFY SENSOR
   ↓
RECALIBRATE IF REQUIRED
```

---

# Engineering Relevance

The 3D-printed components solve problems that are directly connected to Piolín's autonomous performance.

```text
ColorSensorCasing.stl
      ↓
more controlled S4 environment
      ↓
more repeatable floor sensing
```

and:

```text
PIXY_Case1.stl
+
PIXY_Case2.stl
      ↓
repeatable Pixy2.1 installation
      ↓
more consistent vision geometry
```

The manufacturing process is therefore connected directly to:

```text
MECHANICAL DESIGN
      ↓
SENSOR INSTALLATION
      ↓
PERCEPTION
      ↓
SOFTWARE CALIBRATION
      ↓
AUTONOMOUS PERFORMANCE
```

The central manufacturing principle used by PiolínTech is:

> **A 3D-printed component is considered successful only when it can be manufactured, installed consistently, and verified as part of the sensing system it was designed to support.**

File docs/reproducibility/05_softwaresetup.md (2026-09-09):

# 5. Software Setup

<div align="center">

LEGO Mindstorms EV3 installed as Piolín's central controller

<br>

<sub><b>Figure 5.1.</b> Piolín uses the EV3 Brick as the execution platform for both competition programs, while the active software environment changes with the S1 device installed for each round.</sub>

</div>

Piolín uses **two round-specific software configurations** because the Open Challenge and Obstacle Challenge use different hardware on Sensor Port S1 and require different sensor interfaces.

The software architecture follows the same principle as the hardware architecture:

```text
ONE VEHICLE
+
TWO ROUND-SPECIFIC PROGRAMS
```

The current configuration is:

| Challenge | S1 Hardware | Main Software Environment |
| :--- | :--- | :--- |
| Open Challenge | EV3 Gyro Sensor | Pybricks MicroPython |
| Obstacle Challenge | Pixy2.1 | Python 3 + ev3dev2 + SMBus/I2C |

The permanent hardware remains:

```text
Motor A
→ propulsion

Motor B
→ steering

S2
→ LEFT Ultrasonic

S3
→ RIGHT Ultrasonic

S4
→ Color Sensor
```

The software selected for a run must always match the physical device installed on S1.

```text
OPEN SOFTWARE
↔
GYRO ON S1
```

```text
OBSTACLE SOFTWARE
↔
PIXY2.1 ON S1
```

Running the correct code with the wrong S1 hardware should be treated as a **configuration error**, not as a controller-tuning problem.

---

## 5.1 Software Architecture

Piolín deliberately avoids combining every experimental driver and competition mode into one large program.

The preferred project structure separates the two challenge entry points:

```text
src/
│
├── open_challenge.py
│
└── obstacle_challenge.py
```

Conceptually:

```text
OPEN CHALLENGE
      │
      ▼
Pybricks MicroPython
      │
      ├── Motor A
      ├── Motor B
      ├── Gyro S1
      ├── Left US S2
      ├── Right US S3
      └── Color S4
```

while:

```text
OBSTACLE CHALLENGE
      │
      ▼
Python 3 / ev3dev2
      │
      ├── Motor A
      ├── Motor B
      ├── Pixy2.1 S1
      ├── Left US S2
      ├── Right US S3
      └── Color S4
```

This separation mirrors the real hardware and makes each program easier to understand, test, and reproduce.

During development, filenames may differ from the final repository entry points. A known Open development version, for example, may retain a longer experimental filename. Before competition or final repository publication, the known-good program should be copied or promoted into a clearly identified round-specific entry point without losing its Git history.

---

## 5.2 Common EV3 Requirements

Both competition programs run on the LEGO Mindstorms EV3 Brick.

The EV3 environment must be capable of:

```text
running Python-based programs

accessing EV3 motor ports

accessing EV3 sensor ports

reading motor encoders

executing files from the robot filesystem
```

The Obstacle environment additionally needs access to the I2C/SMBus interface used for Pixy2.1 communication.

Before working on either competition program, verify that the EV3 itself is operational:

```text
EV3 powers correctly

battery is installed

filesystem is accessible

program files can be transferred

Python environment launches

motor and sensor devices are visible
```

Software debugging should not begin until these basic platform requirements are working.

---

# 5.3 Hardware Must Match the Software

Before selecting the software environment, identify the active round.

### Open hardware

```text
A  → Large Motor

B  → Medium Motor

S1 → Gyro

S2 → LEFT Ultrasonic

S3 → RIGHT Ultrasonic

S4 → Color Sensor
```

### Obstacle hardware

```text
A  → Large Motor

B  → Medium Motor

S1 → Pixy2.1

S2 → LEFT Ultrasonic

S3 → RIGHT Ultrasonic

S4 → Color Sensor
```

<div align="center">

Piolín Open Challenge wiring configuration

<br>

<sub><b>Figure 5.2.</b> Open software must be used with the Gyro Sensor installed on S1.</sub>

</div>

<div align="center">

Piolín Obstacle Challenge wiring configuration

<br>

<sub><b>Figure 5.3.</b> Obstacle software must be used with Pixy2.1 installed on S1.</sub>

</div>

The following combinations are incorrect:

```text
Open program
+
Pixy on S1
```

```text
Obstacle program
+
Gyro on S1
```

The software should never compensate for an incorrect hardware configuration.

---

# 5.4 Open Challenge Environment

The current Open development path uses **Pybricks MicroPython**.

This environment is responsible for controlling the EV3 hardware used during Open:

```text
Large Motor A

Medium Motor B

Gyro Sensor

two Ultrasonic Sensors

Color Sensor
```

The Open controller uses the sensors for different purposes:

```text
Gyro
→ heading and rotational reference

S2 / S3
→ lateral track geometry

S4
→ course-direction and progression events
```

The known control architecture includes:

```text
gyro initialization

straight heading stabilization

wall-relative correction

color-event processing

corner-state logic

progress counting

parking logic
```

The software should initialize all required hardware before Motor A begins propulsion.

---

## 5.5 Open Startup Sequence

<div align="center">

Piolín EV3 Gyro Sensor installed on S1

<br>

<sub><b>Figure 5.4.</b> The Gyro Sensor must be installed and initialized before the Open controller begins autonomous movement.</sub>

</div>

A reproducible Open startup sequence is:

```text
1. Install the Gyro Sensor on S1.

2. Verify S2 = LEFT Ultrasonic.

3. Verify S3 = RIGHT Ultrasonic.

4. Verify S4 = Color Sensor.

5. Verify Motor A = propulsion.

6. Verify Motor B = steering.

7. Power on the EV3.

8. Load the Open program.

9. Keep Piolín stationary.

10. Initialize sensors.

11. Reset the gyro heading reference.

12. Verify steering center.

13. Place Piolín at the intended starting position.

14. Start the autonomous run.
```

The gyro reference should be established while Piolín is stationary.

The current software concept uses:

```python
gyro.reset_angle(0)
```

or the equivalent operation supported by the active Open implementation.

The important requirement is not the exact syntax alone. It is that the vehicle begins with a known relative heading reference.

---

# 5.6 Running the Open Program

When using an EV3 environment configured for Pybricks MicroPython, a development program may be launched from the EV3 shell using the appropriate Pybricks runner.

A typical development command has the form:

```bash
brickrun -r -- pybricks-micropython <open_program>.py
```

For example, after the final entry point is organized as:

```text
src/open_challenge.py
```

the corresponding command can follow the same pattern using that filename.

The exact working directory depends on where the repository is stored on the EV3.

A program should not be considered correctly installed merely because it starts.

Before track testing, verify that it can read the expected hardware.

---

# 5.7 Open Hardware Test Before Driving

A minimal Open diagnostic should verify:

```text
Motor A responds

Motor B responds

Gyro angle changes when Piolín rotates

S2 reports left-side distance

S3 reports right-side distance

S4 changes when placed over course colors
```

The most important mapping check is:

```text
S2 = LEFT

S3 = RIGHT
```

If these values are reversed in software, the controller can produce physically inverted wall corrections even though the motors and sensors are all functioning.

---

# 5.8 Open Direction State

The current course-direction convention is:

```text
BLUE first
→ COUNTERCLOCKWISE
```

```text
ORANGE first
→ CLOCKWISE
```

The software should initially treat direction as unknown:

```text
direction = UNKNOWN
```

and establish it only after the first valid course-color event.

Once selected:

```text
direction should remain persistent
```

for the run.

The program must not repeatedly invert direction every time another Blue or Orange region is detected.

This direction state determines how the permanent sensors are logically interpreted.

### Counterclockwise

```text
S2 LEFT
→ inner

S3 RIGHT
→ outer
```

### Clockwise

```text
S3 RIGHT
→ inner

S2 LEFT
→ outer
```

The physical sensor mapping remains unchanged.

---

# 5.9 Open Gyro Control

The current Open controller combines gyro information with ultrasonic geometry.

A conceptual control structure is:

```text
wall geometry
      ↓
lateral correction
```

plus:

```text
gyro heading error
      ↓
heading correction
```

followed by:

```text
combined steering request
      ↓
Motor B
```

Current development code has used gyro PD-style stabilization rather than relying on the gyro as a complete navigation system by itself.

Working values inside the current code should be treated as **calibration constants**, not permanent hardware specifications.

The reproducibility requirement is therefore:

```text
copy current known-good values
      ↓
verify hardware geometry
      ↓
recalibrate if mechanical configuration changes
```

rather than assuming a gain value will behave identically on every rebuild.

---

# 5.10 Obstacle Challenge Environment

The Obstacle Challenge requires a different software path because S1 is occupied by Pixy2.1 rather than the EV3 Gyro Sensor.

The current development architecture uses:

```text
Python 3

ev3dev2

SMBus / I2C
```

The EV3 remains responsible for:

```text
drive motor control

steering motor control

ultrasonic sensing

Color Sensor input

state management
```

while the Pixy2.1 interface supplies forward visual block information.

The high-level software structure is:

```text
EV3 PROGRAM
    │
    ├── Motor A
    ├── Motor B
    ├── S2 Left US
    ├── S3 Right US
    ├── S4 Color
    │
    └── Pixy interface
           ↓
        I2C / SMBus
           ↓
        Pixy2.1 S1
```

---

# 5.11 Pixy2.1 Software Interface

<div align="center">

Pixy2.1 directly connected to Piolín EV3 Sensor Port S1

<br>

<sub><b>Figure 5.5.</b> The current Obstacle software communicates with Pixy2.1 through the direct S1 connection.</sub>

</div>

The current architecture no longer uses:

```text
HuskyLens

Arduino Nano

USB-to-Nano bridge
```

for active obstacle vision.

Instead:

```text
Pixy2.1
    ↓
S1
    ↓
EV3
```

The software accesses visual information through the current I2C/SMBus communication path.

The application should obtain block data such as:

```text
signature

x

y

width

height
```

and pass that information into the obstacle-navigation logic.

The vision interface should remain conceptually separate from the steering controller:

```text
read camera
      ↓
select target
      ↓
determine obstacle state
      ↓
calculate steering
```

rather than allowing one raw Pixy value to command Motor B directly.

---

# 5.12 Pixy2.1 Physical Configuration

<div align="center">

Pixy2.1 installed as Piolín forward vision sensor

<br>

<sub><b>Figure 5.6.</b> Pixy2.1 software calibration is valid only for the corresponding physical camera installation.</sub>

</div>

The current Pixy2.1 assembly includes a **3D-printed casing**.

The casing is part of the active Obstacle Challenge installation and should remain installed while final signatures and visual parameters are calibrated.

It does not require a software driver of its own, but changing the casing or camera orientation can change:

```text
lighting conditions

camera field of view

target coordinates

apparent target geometry
```

Therefore software calibration should always be associated with the current physical camera installation.

---

# 5.13 Pixy Signature Setup

The current visual mapping is:

| Pixy Signature | Target | Software Meaning |
| :---: | :--- | :--- |
| `1` | Pink | Parking reference |
| `2` | Red | Pass RIGHT |
| `3` | Green | Pass LEFT |

The camera training and the EV3 program must use the same mapping.

The required obstacle rules are:

```text
signature 2
→ RED
→ PASS RIGHT
```

```text
signature 3
→ GREEN
→ PASS LEFT
```

A common configuration failure would be:

```text
Pixy trained:
sig2 = Green
```

while:

```text
EV3 code assumes:
sig2 = Red
```

The software could then be internally correct while producing the wrong physical maneuver.

Signature mapping should therefore be verified before steering calibration.

---

# 5.14 Running the Obstacle Program

The Obstacle program uses the standard Python environment associated with its ev3dev2 implementation.

A typical shell execution pattern is:

```bash
python3 <obstacle_program>.py
```

or the equivalent launch method configured on the EV3.

If the final repository entry point is:

```text
src/obstacle_challenge.py
```

that file should be the clearly documented program used for the current Obstacle configuration.

Before full execution, verify that the software can:

```text
initialize ev3dev2 motors

read S2

read S3

read S4

open the Pixy I2C/SMBus interface

receive valid Pixy data
```

A failure in Pixy communication should be solved before obstacle-navigation parameters are modified.

---

# 5.15 Obstacle Startup Sequence

A reproducible startup process is:

```text
1. Power down Piolín before changing S1.

2. Remove the Gyro Sensor.

3. Install the Pixy2.1 assembly.

4. Verify the Pixy 3D-printed casing is secure.

5. Connect Pixy2.1 to S1.

6. Verify S2 = LEFT Ultrasonic.

7. Verify S3 = RIGHT Ultrasonic.

8. Verify S4 = Color Sensor.

9. Verify Motors A and B.

10. Power on the EV3.

11. Launch the Obstacle software environment.

12. Verify Pixy communication.

13. Verify Red / Green / Pink signature mapping.

14. Test raw ultrasonic readings.

15. Test steering direction.

16. Begin low-speed obstacle testing.
```

The robot should not proceed directly to a full-speed run after changing the S1 device.

A short hardware/software verification catches many configuration errors immediately.

---

# 5.16 Obstacle Target Processing

The software should not assume that the first block returned by Pixy is always the obstacle Piolín should follow.

A more robust pipeline is:

```text
read blocks
    ↓
reject invalid signatures
    ↓
evaluate candidate relevance
    ↓
select active pillar
    ↓
temporarily lock target
    ↓
execute maneuver
    ↓
confirm pass
    ↓
release target
```

Target relevance can use information such as:

```text
signature

x

y

width

height

current state

previous target
```

The final scoring or selection formula is still under development and should therefore not be documented as a fully validated final algorithm until testing supports it.

---

# 5.17 Vision Coordinates and Passing Direction

The software must keep two concepts separate.

```text
PIXY x
→ where the target appears in the image
```

and:

```text
signature
→ which side Piolín is required to pass
```

The rule is always:

```text
RED
→ RIGHT
```

```text
GREEN
→ LEFT
```

regardless of whether the target appears:

```text
left of image center

centered

right of image center
```

The coordinate can influence **how strongly** or **how early** the robot reacts.

It must not invert the competition rule.

---

# 5.18 Obstacle Control Arbitration

The Obstacle program contains multiple possible steering influences.

These can include:

```text
normal wall correction

wall safety

pillar avoidance

countersteering

post-pillar recovery

corner control
```

The software should not simply add all of them with equal authority.

A state-dependent priority is more understandable.

Conceptually:

```text
NORMAL
→ geometry control
```

```text
PILLAR ACTIVE
→ obstacle objective dominates
→ wall safety remains active
```

```text
PILLAR PASSED
→ countersteer
→ ultrasonic recovery
```

```text
RECOVERED
→ normal control resumes
```

This is especially important because allowing wall following to fight obstacle avoidance can make correct Pixy detections appear to produce the wrong steering behavior.

---

# 5.19 Shared Software Conventions

Even though the two programs use different software environments, some conventions should remain identical.

### Motor mapping

```text
A = propulsion

B = steering
```

### Ultrasonic mapping

```text
S2 = LEFT

S3 = RIGHT
```

### Floor sensor

```text
S4 = Color Sensor
```

### Obstacle rules

```text
RED = pass RIGHT

GREEN = pass LEFT
```

These conventions should not be redefined independently in different source files.

A shared engineering vocabulary reduces errors when switching between round-specific programs.

---

# 5.20 Recommended Source-Code Organization

A clean final repository can organize software by responsibility.

For example:

```text
src/
│
├── open_challenge.py
│
├── obstacle_challenge.py
│
└── README.md
```

If helper modules are later separated, the structure could expand conceptually to:

```text
src/
│
├── open_challenge.py
├── obstacle_challenge.py
│
├── control/
│   ├── steering
│   └── drive
│
├── sensors/
│   ├── ultrasonic
│   ├── color
│   ├── gyro
│   └── pixy
│
└── utilities/
```

The exact module structure should reflect the actual code rather than creating empty architecture only for appearance.

The important reproducibility requirement is that another reader can identify:

```text
which file starts Open

which file starts Obstacles
```

without searching through experimental programs.

---

# 5.21 Development Files vs. Current Entry Points

Piolín development naturally produces files such as:

```text
test versions

calibration programs

experimental steering programs

camera tests

old controller iterations
```

These are valuable engineering records, but they should not all appear to have equal status.

A useful distinction is:

```text
CURRENT ENTRY POINT
→ program intended for present round testing
```

```text
EXPERIMENTAL
→ active development / subsystem testing
```

```text
LEGACY
→ architecture no longer used
```

For example, old HuskyLens/Nano code should not sit beside the current Pixy program without clear legacy labeling.

This prevents another builder from reproducing the wrong architecture.

---

# 5.22 Calibration Files

Small diagnostic programs are useful during setup.

Examples include programs that only:

```text
print S2/S3 distance

print Color Sensor values

print gyro angle

read Pixy blocks

move Motor B to center

test Motor A forward/reverse
```

These programs can be easier to debug than the complete autonomous controller.

The setup philosophy is:

```text
TEST EACH INTERFACE
        ↓
THEN RUN COMPLETE CONTROLLER
```

A full autonomous program is a poor first diagnostic for a newly rebuilt system because too many variables are active simultaneously.

---

# 5.23 Suggested Software Verification Sequence

After transferring the software to the EV3, verify it in this order:

```text
1. Program starts without import/runtime errors.

2. Motor A object initializes.

3. Motor B object initializes.

4. S2 can be read.

5. S3 can be read.

6. S4 can be read.

7. Correct S1 device can be read.

8. Motor A direction is correct.

9. Motor B left/right direction is correct.

10. Steering center is correct.

11. Sensor values are physically plausible.

12. Low-speed test succeeds.

13. Only then run autonomous navigation.
```

This order isolates configuration problems before they become track collisions.

---

# 5.24 Software Setup After a Round Change

Changing from Open to Obstacles is not only a hardware action.

The active runtime also changes.

### Open → Obstacles

```text
power down
      ↓
replace Gyro with Pixy
      ↓
verify wiring
      ↓
boot EV3
      ↓
select Python 3 / ev3dev2 Obstacle program
      ↓
verify SMBus/I2C camera communication
      ↓
test signatures
      ↓
run Obstacles
```

### Obstacles → Open

```text
power down
      ↓
replace Pixy with Gyro
      ↓
verify wiring
      ↓
boot EV3
      ↓
select Pybricks Open program
      ↓
initialize gyro
      ↓
reset heading
      ↓
run Open
```

A round conversion is not complete until both the **hardware and software environment** correspond to the same challenge.

---

# 5.25 Git and Version Control

Reproducibility requires knowing which source code produced a particular result.

A useful workflow is:

```text
modify code
    ↓
test
    ↓
record observation
    ↓
keep or reject change
    ↓
commit meaningful version
```

Important known-good versions should be identifiable through Git rather than only through filenames such as:

```text
final2.py

finalfinal.py

newnewworking.py
```

Development filenames are understandable during rapid testing, but the final repository should use Git history and descriptive entry points to preserve traceability.

---

# 5.26 Configuration Constants

Controller values should be grouped clearly rather than scattered throughout the program.

Examples include:

```text
drive speed

steering limits

wall target

wall safety threshold

gyro gains

color thresholds

corner parameters

Pixy signature IDs

visual relevance limits

target-lock parameters

parking parameters
```

A reader should be able to distinguish:

```text
CALIBRATION VALUES
```

from:

```text
CONTROL LOGIC
```

This makes reproduction and retuning significantly easier.

Working values should be described as current tuning values until repeated testing supports them as final calibrated parameters.

---

# 5.27 Units

Software should use consistent units and make them obvious.

Examples include:

```text
millimeters

degrees

motor degrees

milliseconds

pixels
```

Variables should avoid ambiguous names such as:

```text
distance
```

when the actual quantity could be:

```text
distance_mm
```

or:

```text
motor_deg
```

Likewise, Pixy coordinates should remain visibly separate from physical distances.

```text
pixy_x
```

is an image coordinate.

It is not automatically a centimeter measurement.

Clear units reduce software errors and improve reproducibility.

---

# 5.28 Startup Safety

A software failure during initialization should preferably occur **before propulsion begins**.

The controller should verify critical devices before Motor A starts a normal run.

Examples include:

```text
required S1 device available?

S2 available?

S3 available?

S4 available?

Motor B initialized?
```

If a critical sensor cannot be initialized, continuing immediately at competition speed can create an avoidable collision.

The exact failure-handling implementation can evolve, but the architectural principle is:

> **Validate the control system before enabling normal motion.**

---

# 5.29 Debug Output

Diagnostic output is useful during development.

A compact line might include values such as:

```text
direction

state

corner count

S2

S3

gyro angle
```

during Open, or:

```text
state

target signature

x

y

width

height

S2

S3
```

during Obstacles.

Debug output should be concise enough that it does not make the control loop unnecessarily difficult to observe or maintain.

For competition code, unnecessary development logging can be reduced once the controller is validated.

---

# 5.30 Common Open Setup Errors

| Symptom | First Software Check |
| :--- | :--- |
| Program does not start | Pybricks runtime / syntax / file location |
| Gyro unavailable | S1 mapping and Open hardware |
| Heading starts incorrectly | Gyro initialization / reset |
| Robot corrects toward wrong wall | S2/S3 mapping or steering sign |
| Blue sets wrong direction | Color-direction mapping |
| Orange sets wrong direction | Color-direction mapping |
| Direction changes later | Persistent state implementation |
| Corner counted twice | Color-event / state logic |
| Straight driving oscillates | Control tuning after hardware verification |
| Same program changed behavior after rebuild | Recalibrate mechanics/sensors before rewriting logic |

---

# 5.31 Common Obstacle Setup Errors

| Symptom | First Software Check |
| :--- | :--- |
| `ev3dev2` import fails | Python environment / package installation |
| SMBus interface unavailable | Obstacle software environment |
| Pixy returns no blocks | S1 communication, signatures, lighting |
| Red becomes left maneuver | Signature/rule mapping |
| Green becomes right maneuver | Signature/rule mapping |
| Distant pillar changes steering | Relevance logic |
| Target changes during pass | Target-lock state |
| Camera loses target and robot reverses decision | Target-loss handling |
| Correct pillar chosen but steering seems opposed | Control arbitration / steering sign |
| Pillar passed but robot remains locked | Pass-confirmation / release state |
| Robot avoids pillar then hits wall | Recovery logic / ultrasonic arbitration |

This distinction helps prevent installation problems from being treated as vision-model or steering problems.

---

# 5.32 Legacy Software

The current software setup should not require legacy vision components.

Older Piolín development may contain software for:

```text
HuskyLens

Arduino Nano

USB serial bridge

front ultrasonic

older Pixy configurations
```

These programs should remain separated from current competition software.

The correct current distinction is:

```text
CURRENT OPEN
→ Gyro + Pybricks
```

```text
CURRENT OBSTACLES
→ Pixy2.1 + ev3dev2/SMBus
```

Legacy code is useful to explain the engineering evolution but should not be included in the current installation procedure.

---

# 5.33 Setup Checklist — Open Challenge

Before Open testing, verify:

| Check | Required State |
| :--- | :--- |
| Runtime | Pybricks MicroPython |
| Program | Current Open entry point |
| Motor A | Available and correct direction |
| Motor B | Available and centered |
| S1 | Gyro |
| S2 | LEFT Ultrasonic |
| S3 | RIGHT Ultrasonic |
| S4 | Color Sensor |
| Pixy2.1 | Not active |
| Gyro initialization | Completed while stationary |
| Direction state | Initially unknown |
| Blue mapping | Counterclockwise |
| Orange mapping | Clockwise |
| Low-speed hardware test | Completed |

Only after these checks should a complete Open run begin.

---

# 5.34 Setup Checklist — Obstacle Challenge

Before Obstacle testing, verify:

| Check | Required State |
| :--- | :--- |
| Runtime | Python 3 / ev3dev2 |
| Vision interface | SMBus/I2C available |
| Program | Current Obstacle entry point |
| Motor A | Available and correct direction |
| Motor B | Available and centered |
| S1 | Pixy2.1 |
| S2 | LEFT Ultrasonic |
| S3 | RIGHT Ultrasonic |
| S4 | Color Sensor |
| Gyro | Not active |
| Pixy casing | Installed and secure |
| `sig1` | Pink |
| `sig2` | Red |
| `sig3` | Green |
| Red rule | Pass RIGHT |
| Green rule | Pass LEFT |
| Raw camera test | Successful |
| Low-speed maneuver test | Completed |

---

# 5.35 Complete Software Deployment Flow

The reproducible software workflow can be summarized as:

```text
                    SELECT ROUND
                         │
              ┌──────────┴──────────┐
              ▼                     ▼
            OPEN                OBSTACLES
              │                     │
              ▼                     ▼
         Gyro on S1           Pixy2.1 on S1
              │                     │
              ▼                     ▼
        Pybricks runtime      Python 3 / ev3dev2
              │                + SMBus/I2C
              │                     │
              ▼                     ▼
        load Open code       load Obstacle code
              │                     │
              ▼                     ▼
         verify sensors       verify sensors
              │                     │
              ▼                     ▼
        calibrate heading     verify signatures
              │                     │
              └──────────┬──────────┘
                         ▼
                 LOW-SPEED TEST
                         │
                         ▼
                 MANEUVER TEST
                         │
                         ▼
                    FULL RUN
                         │
                         ▼
                  RECORD RESULT
```

The central rule is simple:

```text
hardware configuration
+
runtime
+
source code
+
calibration
```

must all describe the same version of Piolín.

---

# 5.36 Final Engineering Assessment

Piolín's software architecture reflects the same modular philosophy used in its hardware.

Most of the robot remains constant:

```text
Motor A

Motor B

S2

S3

S4
```

while the specialized S1 device changes according to the challenge.

The software follows that distinction rather than hiding it.

### Open

```text
Pybricks MicroPython
+
Gyro
+
Ultrasonics
+
Color Sensor
```

### Obstacles

```text
Python 3
+
ev3dev2
+
SMBus/I2C
+
Pixy2.1
+
Ultrasonics
+
Color Sensor
```

This separation reduces unnecessary dependencies and keeps each controller aligned with the hardware that is actually installed.

The current Pixy2.1 assembly, including its **3D-printed casing**, should remain physically unchanged when final visual calibration values are recorded. Likewise, the Color Sensor casing is part of the current S4 calibration.

The software setup process therefore does not end when a Python file successfully executes.

A reproducible Piolín software installation requires:

```text
correct hardware

correct runtime

correct port mapping

correct source-code version

correct sensor calibration

correct startup procedure
```

The final principle is:

> **The program running on the EV3 must describe the same physical robot that is actually connected to it.**

Keeping the Open and Obstacle software paths clearly separated makes Piolín easier to deploy, debug, reproduce, and improve without mixing assumptions from two different competition configurations.

---

<div align="center">

### [← Back to PiolínTech Main README](../../README.md)

</div>

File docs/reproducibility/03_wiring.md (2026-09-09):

# 3. Wiring and Port Configuration

<div align="center">

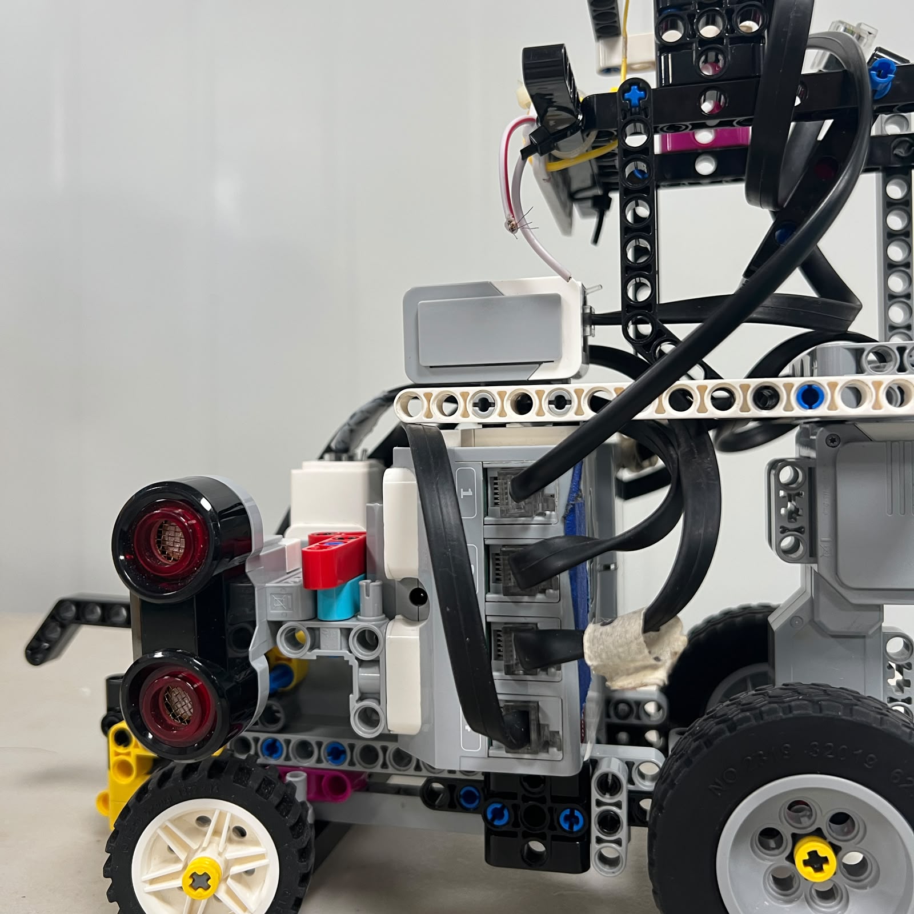
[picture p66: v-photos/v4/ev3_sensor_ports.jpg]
LEGO Mindstorms EV3 sensor ports used by Piolín


<br>

<sub><b>Figure 3.1.</b> Piolín uses the four EV3 sensor ports with a fixed S2/S3/S4 mapping and a round-specific device on S1.</sub>

</div>

Piolín uses the LEGO Mindstorms EV3 Brick as the central connection point for its motors, sensors, and power system. The wiring architecture was deliberately simplified so that most connections remain unchanged between the **Open Challenge** and the **Obstacle Challenge**.

The permanent port assignments are:

```text
MOTOR A
→ propulsion

MOTOR B
→ steering

S2
→ LEFT Ultrasonic Sensor

S3
→ RIGHT Ultrasonic Sensor

S4
→ Color Sensor
```

Only Sensor Port S1 changes between competition rounds:

```text
OPEN
S1 → EV3 Gyro Sensor
```

```text
OBSTACLES
S1 → Pixy2.1
```

The Gyro Sensor and Pixy2.1 are **never installed simultaneously** in the current Piolín architecture.

This is the most important wiring rule for reproducing the current robot.

---

## 3.1 Complete Port Map

The current electrical mapping can be summarized as:

| EV3 Port | Open Challenge | Obstacle Challenge | Physical Role |
| :---: | :--- | :--- | :--- |
| A | EV3 Large Motor | EV3 Large Motor | Rear propulsion |
| B | EV3 Medium Motor | EV3 Medium Motor | Front steering |
| C | Unused | Unused | — |
| D | Unused | Unused | — |
| S1 | EV3 Gyro Sensor | Pixy2.1 | Round-specific perception |
| S2 | Left Ultrasonic Sensor | Left Ultrasonic Sensor | Left lateral geometry |
| S3 | Right Ultrasonic Sensor | Right Ultrasonic Sensor | Right lateral geometry |
| S4 | EV3 Color Sensor | EV3 Color Sensor | Floor/course-state sensing |

The fixed mapping should be preserved in both hardware and software.

```text
A  = DRIVE

B  = STEERING

S2 = LEFT

S3 = RIGHT

S4 = COLOR
```

This convention should never be inverted only because Piolín changes from clockwise to counterclockwise navigation.

---

# 3.2 Motor Wiring

<div align="center">

EV3 motor ports used by Piolín

<br>

<sub><b>Figure 3.2.</b> Piolín uses only Motor Ports A and B.</sub>

</div>

Piolín uses two LEGO Mindstorms EV3 motors.

### Port A — propulsion

```text
EV3 Port A
      ↓
EV3 Large Motor
      ↓
rear drivetrain
      ↓
rear wheels
```

<div align="center">

Piolín EV3 Large Motor connected as the propulsion actuator

<br>

<sub><b>Figure 3.3.</b> Motor A is the only propulsion actuator in the current vehicle.</sub>

</div>

The Large Motor drives the rear wheels and is responsible for:

```text
forward motion

reverse motion

approach speed

course travel

parking displacement
```

### Port B — steering

```text
EV3 Port B
      ↓
EV3 Medium Motor
      ↓
Ackermann-style steering linkage
      ↓
front wheels
```

<div align="center">

Piolín EV3 Medium Motor used for front steering

<br>

<sub><b>Figure 3.4.</b> Motor B is dedicated to the front steering mechanism.</sub>

</div>

Ports C and D are not required in the current two-motor architecture.

This wiring is identical for both competition rounds.

---

# 3.3 Permanent Sensor Wiring

Three sensor connections remain unchanged regardless of round:

```text
S2 → LEFT Ultrasonic

S3 → RIGHT Ultrasonic

S4 → Color Sensor
```

<div align="center">

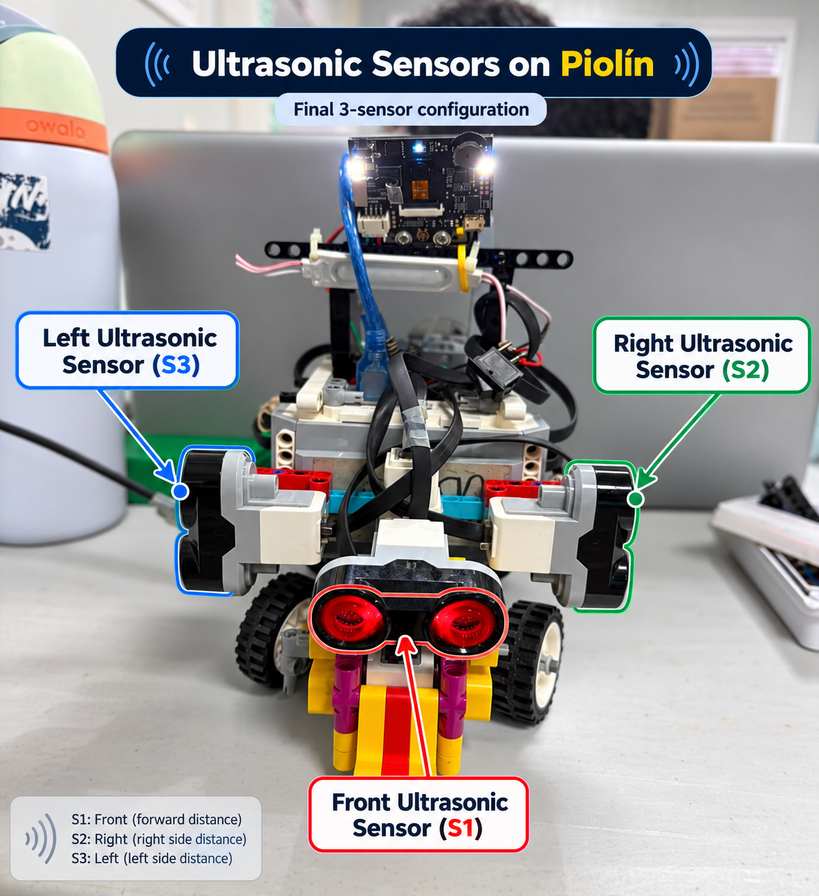
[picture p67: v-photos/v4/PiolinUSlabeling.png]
Piolín ultrasonic sensor mapping showing S2 left and S3 right


<br>

<sub><b>Figure 3.5.</b> Permanent physical ultrasonic mapping: S2 is LEFT and S3 is RIGHT.</sub>

</div>

The physical identity must remain constant.

The software may later interpret one sensor as:

```text
INNER
```

and the other as:

```text
OUTER
```

depending on course direction, but the electrical port assignment does not change.

This avoids a common source of navigation errors where the software assumes the opposite side from the actual connected sensor.

---

# 3.4 Left Ultrasonic — S2

<div align="center">

Piolín left ultrasonic sensor connected to EV3 S2

<br>

<sub><b>Figure 3.6.</b> Left lateral EV3 Ultrasonic Sensor connected permanently to S2.</sub>

</div>

The S2 cable should connect:

```text
LEFT Ultrasonic Sensor
        ↓
EV3 Sensor Port S2
```

Its physical role remains:

```text
LEFT-SIDE GEOMETRY
```

in both rounds.

During counterclockwise Open navigation it becomes the logical inner sensor.

During clockwise navigation it becomes the logical outer sensor.

The physical connection itself never changes.

---

# 3.5 Right Ultrasonic — S3

<div align="center">

Piolín right ultrasonic sensor connected to EV3 S3

<br>

<sub><b>Figure 3.7.</b> Right lateral EV3 Ultrasonic Sensor connected permanently to S3.</sub>

</div>

The S3 connection is:

```text
RIGHT Ultrasonic Sensor
        ↓
EV3 Sensor Port S3
```

Its permanent physical responsibility is:

```text
RIGHT-SIDE GEOMETRY
```

As with S2, only its logical inner/outer interpretation changes according to course direction.

---

# 3.6 Color Sensor — S4

<div align="center">

Piolín Color Sensor installed and connected to S4

<br>

<sub><b>Figure 3.8.</b> The downward-facing Color Sensor remains permanently connected to Sensor Port S4.</sub>

</div>

The Color Sensor connection is:

```text
EV3 Color Sensor
        ↓
Sensor Port S4
```

Its role remains constant in both rounds:

```text
floor detection

Blue / Orange landmarks

course-state information

progress support
```

The sensor is installed with its current light-isolation casing.

The casing does not create a separate electrical connection, but it is part of the calibrated S4 installation and should remain mechanically secure.

---

# 3.7 Open Challenge Wiring

<div align="center">

Complete Piolín Open Challenge wiring

<br>

<sub><b>Figure 3.9.</b> Complete current wiring configuration for the Open Challenge.</sub>

</div>

For the Open Challenge, the complete wiring is:

```text
                   EV3 BRICK

        MOTOR PORTS          SENSOR PORTS

        A → Large Motor      S1 → Gyro
        B → Medium Motor     S2 → Left US
        C → unused           S3 → Right US
        D → unused           S4 → Color
```

The corresponding functional architecture is:

```text
                 EV3
                  │
        ┌─────────┼─────────┐
        │                   │
        ▼                   ▼
     MOTORS               SENSORS
        │                   │
   ┌────┴────┐       ┌──────┼──────┬──────┐
   │         │       │      │      │      │
   ▼         ▼       ▼      ▼      ▼      ▼
   A         B       S1     S2     S3     S4
   │         │       │      │      │      │
 Large    Medium    Gyro   Left   Right  Color
 Drive    Steering          US     US
```

This configuration is used only for the Open Challenge.

---

# 3.8 Gyro Connection — Open S1

<div align="center">

EV3 Gyro Sensor connected to S1 in Piolín Open configuration

<br>

<sub><b>Figure 3.10.</b> S1 is occupied by the EV3 Gyro Sensor during Open.</sub>

</div>

The Open S1 path is:

```text
EV3 Gyro Sensor
       ↓
EV3 Sensor Port S1
```

The gyro provides:

```text
heading reference

rotation information

straight-line stabilization support

corner-progress information
```

Its physical orientation relative to the robot should remain unchanged after calibration.

<div align="center">

Piolín Gyro Sensor orientation relative to the chassis

<br>

<sub><b>Figure 3.11.</b> The gyro orientation is part of the reproducible Open installation.</sub>

</div>

A correctly connected gyro that has been physically rotated into a different orientation can still produce incorrect navigation behavior.

Therefore wiring reproduction must include both:

```text
correct port
+
correct physical installation
```

---

# 3.9 Obstacle Challenge Wiring

<div align="center">

Complete Piolín Obstacle Challenge wiring

<br>

<sub><b>Figure 3.12.</b> Complete current wiring configuration for the Obstacle Challenge.</sub>

</div>

For the Obstacle Challenge:

```text
                   EV3 BRICK

        MOTOR PORTS          SENSOR PORTS

        A → Large Motor      S1 → Pixy2.1
        B → Medium Motor     S2 → Left US
        C → unused           S3 → Right US
        D → unused           S4 → Color
```

The functional architecture becomes:

```text
                 EV3
                  │
        ┌─────────┼─────────┐
        │                   │
        ▼                   ▼
     MOTORS               SENSORS
        │                   │
   ┌────┴────┐       ┌──────┼──────┬──────┐
   │         │       │      │      │      │
   ▼         ▼       ▼      ▼      ▼      ▼
   A         B       S1     S2     S3     S4
   │         │       │      │      │      │
 Large    Medium    Pixy   Left   Right  Color
 Drive    Steering  2.1     US     US
```

The Gyro Sensor must not remain connected in this configuration.

---

# 3.10 Pixy2.1 Connection — Obstacle S1

<div align="center">

Pixy2.1 connected to EV3 S1

<br>

<sub><b>Figure 3.13.</b> Pixy2.1 occupies Sensor Port S1 during the Obstacle Challenge.</sub>

</div>

The current vision connection is:

```text
Pixy2.1
    ↓
Pixy connection cable
    ↓
EV3 Sensor Port S1
```

The same physical interface is used for the current communication and power connection to the camera during the Obstacle configuration.

<div align="center">

Current cable used between Pixy2.1 and the EV3

<br>

<sub><b>Figure 3.14.</b> Current connection cable used in Piolín's direct Pixy2.1 integration.</sub>

</div>

The current software communicates with Pixy2.1 through an I2C/SMBus-style interface.

The repository should not invent a separate internal wire or connector pinout unless that pinout has been physically verified from the actual cable.

For reproduction, the authoritative physical reference is the actual connection shown in the V4 photographs.

---

# 3.11 Pixy2.1 Physical Installation

The current Pixy2.1 also includes a **3D-printed casing**.

The casing does not change the EV3 port mapping:

```text
Pixy2.1
→ still S1
```

but it is part of the current mechanical camera installation.

The casing should remain installed because it contributes to:

```text
camera protection

mounting repeatability

physical integration

more controlled optical conditions
```

The exact camera orientation and casing position should be preserved when comparing calibrated visual behavior.

The repository does not currently use a separate image filename specifically for this casing, so no nonexistent image is referenced here.

---

# 3.12 Power Distribution

<div align="center">

LEGO Mindstorms EV3 Rechargeable DC Battery 45501

<br>

<sub><b>Figure 3.15.</b> The EV3 Rechargeable DC Battery 45501 is the central power source for Piolín.</sub>

</div>

Piolín uses the LEGO Mindstorms EV3 Rechargeable DC Battery **45501** installed in the EV3 Brick.

The high-level power architecture is:

```text
EV3 Battery 45501
       ↓
EV3 Brick
       │
       ├── Motor A
       ├── Motor B
       ├── S1 device
       ├── S2 Ultrasonic
       ├── S3 Ultrasonic
       └── S4 Color Sensor
```

The current competition architecture does not use:

```text
external drive battery

separate Pixy battery

Arduino Nano power system

permanent external buck converter
```

During Obstacles, Pixy2.1 operates through the current EV3 S1 connection rather than through a separate external power architecture.

This keeps the competition wiring significantly simpler than earlier prototypes.

---

# 3.13 Round Conversion Procedure

Because the two configurations differ only at S1 and in their corresponding software environment, conversion between rounds should be controlled and simple.

### Open → Obstacles

```text
1. Power down Piolín.

2. Disconnect the Gyro Sensor from S1.

3. Install the Pixy2.1 assembly.

4. Verify the Pixy 3D-printed casing is secure.

5. Connect Pixy2.1 to S1 using the current connection cable.

6. Leave S2, S3, and S4 unchanged.

7. Leave Motors A and B unchanged.

8. Start the Obstacle Challenge software environment.

9. Verify Pixy communication before driving.
```

### Obstacles → Open

```text
1. Power down Piolín.

2. Disconnect Pixy2.1 from S1.

3. Remove the round-specific Pixy assembly as required.

4. Install the EV3 Gyro Sensor.

5. Connect the Gyro Sensor to S1.

6. Verify its physical orientation.

7. Leave S2, S3, and S4 unchanged.

8. Leave Motors A and B unchanged.

9. Start the Open Challenge software.

10. Reset and verify the gyro before driving.
```

The robot should not be rewired while actively running.

---

# 3.14 Why Only S1 Changes

The decision to make S1 modular reduces the number of variables affected when the robot changes competition rounds.

Without this architecture, the team might need to change:

```text
multiple sensors

multiple port assignments

additional controllers

external wiring
```

Instead, Piolín changes:

```text
one specialized sensor
+
its corresponding software interface
```

while preserving:

```text
propulsion

steering

lateral sensing

floor sensing

battery

EV3 controller
```

This makes round conversion easier to verify and reduces the chance of introducing accidental wiring changes.

---

# 3.15 Current Wiring vs. Legacy Wiring

Earlier Piolín prototypes used or tested additional hardware such as:

```text
HuskyLens

Arduino Nano

front ultrasonic sensor

different camera interfaces

different ultrasonic orientations
```

Those connections are **not part of the current V4 competition wiring**.

The current system is:

### Open

```text
A  → Large Motor
B  → Medium Motor

S1 → Gyro
S2 → Left US
S3 → Right US
S4 → Color
```

### Obstacles

```text
A  → Large Motor
B  → Medium Motor

S1 → Pixy2.1
S2 → Left US
S3 → Right US
S4 → Color
```

A reproduction of the current robot should not add:

```text
Arduino Nano

HuskyLens

permanent front ultrasonic
```

simply because they appear in older development records.

Those belong to the legacy engineering history.

---

# 3.16 Wiring Verification Before Startup

Before running any autonomous program, the hardware mapping should be verified physically.

### Common checks

```text
A connected to Large Drive Motor?

B connected to Medium Steering Motor?

S2 connected to LEFT Ultrasonic?

S3 connected to RIGHT Ultrasonic?

S4 connected to Color Sensor?
```

### Open-specific checks

```text
Gyro connected to S1?

Pixy disconnected?

Gyro orientation correct?
```

### Obstacle-specific checks

```text
Pixy connected to S1?

Gyro disconnected?

Pixy connection cable secure?

Pixy 3D casing secure?
```

The correct software should only be started after the corresponding hardware configuration has been verified.

---

# 3.17 Software and Wiring Must Agree

A physical connection is only correct when the source code expects the same mapping.

For example:

```text
PHYSICAL

S2 = LEFT
S3 = RIGHT
```

must match:

```text
SOFTWARE

left_sensor  = S2
right_sensor = S3
```

If they become swapped in code:

```text
left-wall error
```

can create:

```text
right-side steering response
```

even though every physical cable remains correctly connected.

The same requirement applies to S1.

```text
Open software
→ expects Gyro
```

```text
Obstacle software
→ expects Pixy2.1
```

Running the wrong software environment with the wrong S1 configuration should be treated as a configuration error, not a navigation-tuning problem.

---

# 3.18 Visual Wiring References

<div align="center">

Top view of Piolín Open configuration

<br>

<sub><b>Figure 3.16.</b> Open configuration showing the common vehicle hardware and round-specific Gyro installation.</sub>

</div>

<div align="center">

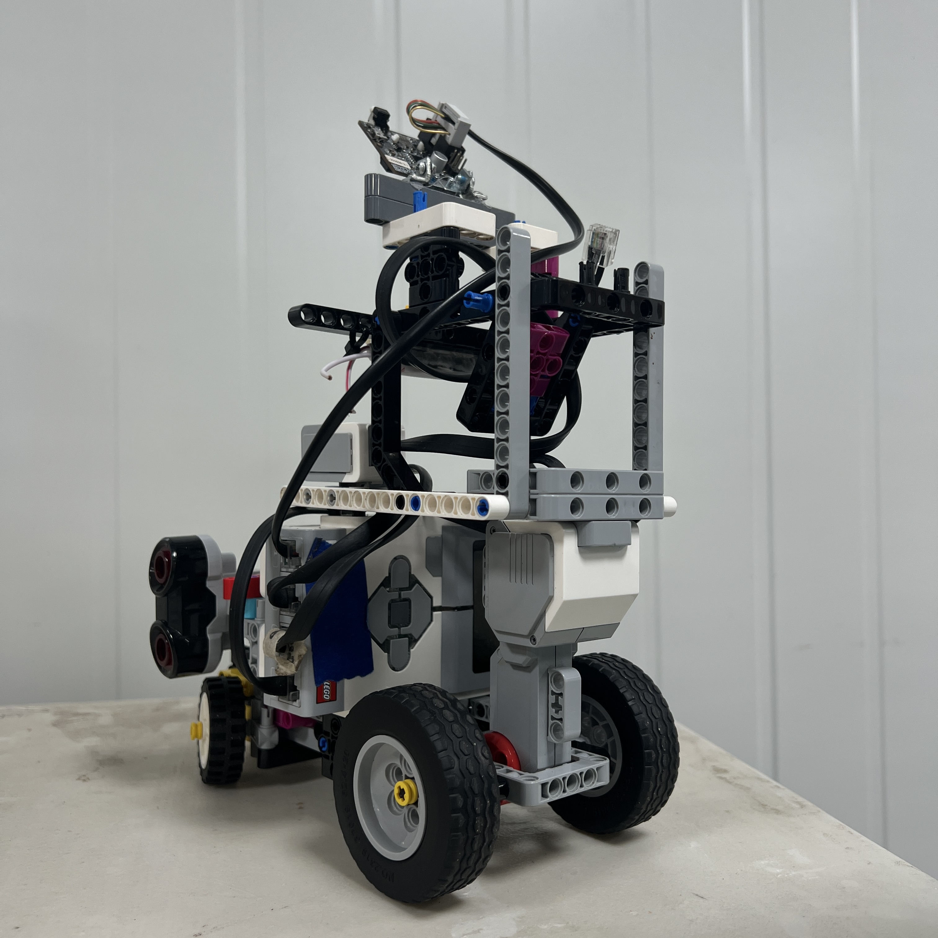
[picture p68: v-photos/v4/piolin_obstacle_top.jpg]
Top view of Piolín Obstacle configuration


<br>

<sub><b>Figure 3.17.</b> Obstacle configuration retains the same drivetrain and permanent sensors while replacing the S1 device with Pixy2.1.</sub>

</div>

These views help verify that round conversion does not require rebuilding the complete vehicle.

The most important visible difference is the specialized S1 sensing assembly.

---

# 3.19 Wiring Failure Diagnosis

| Symptom | First Wiring Check |
| :--- | :--- |
| Piolín does not drive | Port A and Large Motor cable |
| Steering does not respond | Port B and Medium Motor cable |
| Robot steers opposite to wall correction | Verify S2 LEFT / S3 RIGHT in both wiring and code |
| Left ultrasonic unavailable | S2 connection |
| Right ultrasonic unavailable | S3 connection |
| Color Sensor unavailable | S4 connection |
| Open gyro unavailable | S1 Gyro connection |
| Open program sees unexpected S1 behavior | Confirm Pixy is not installed |
| Pixy unavailable | S1 connection, cable, Obstacle software |
| Obstacle code fails after round change | Confirm Gyro was replaced by Pixy |
| Pixy behavior changes after rebuild | Check physical camera/casing installation |
| Sensor data disappears intermittently | Inspect cable seating and strain |
| Correct wiring but wrong behavior | Check software mapping and calibration next |

A useful diagnostic order is:

```text
1. Verify correct round.

2. Verify physical port.

3. Verify cable seating.

4. Verify sensor identity.

5. Read raw device output.

6. Verify software mapping.

7. Only then tune navigation.
```

---

# 3.20 Cable Management and Mechanical Protection

Wiring must remain clear of moving mechanical components.

Particular attention should be given to cables near:

```text
front steering

Motor B linkage

rear drivetrain

wheels

sensor mounts
```

A cable should not:

```text
limit steering travel

rub against a wheel

enter drivetrain motion

pull a sensor out of orientation
```

Cable routing is therefore part of mechanical reliability even though the cable itself is an electrical component.

The Pixy2.1 cable deserves particular attention because the camera is mounted on the front structure and must remain mechanically stable.

The 3D-printed Pixy casing can support the physical integration of the camera, but the cable should still be routed so that it does not apply enough force to change the camera orientation.

---

# 3.21 What Must Not Be Assumed

This document intentionally does **not** invent unverified low-level electrical information.

For example, the repository should not publish an assumed custom Pixy cable pinout unless it has been verified from the actual hardware.

Similarly, no unsupported claim is made here about:

```text
individual connector voltages

internal current consumption

specific wire colors

unverified I2C pin assignment

custom adapter circuitry
```

The reproducible facts currently established are:

```text
Pixy2.1 uses the current direct S1 connection.

The current software communicates with it through I2C/SMBus.

The same physical connection provides the active camera interface in the Obstacle configuration.

The actual cable is documented photographically.
```

Where lower-level electrical details become necessary, they should be measured or verified before being added as specifications.

---

# 3.22 Complete Current Wiring Architecture

The final current wiring can be represented as:

```text
                         EV3 BATTERY 45501
                                │
                                ▼
                           ┌─────────┐
                           │   EV3   │
                           └────┬────┘
                                │
             ┌──────────────────┼──────────────────┐
             │                                     │
             ▼                                     ▼
        MOTOR OUTPUTS                         SENSOR INPUTS
             │                                     │
       ┌─────┴─────┐                 ┌─────────────┼─────────────┐
       │           │                 │             │             │
       ▼           ▼                 ▼             ▼             ▼
       A           B                S2            S3            S4
       │           │                 │             │             │
   Large Motor  Medium Motor      Left US       Right US       Color
       │           │
       ▼           ▼
    DRIVE       STEERING

                         ROUND-SPECIFIC S1

                    ┌─────────┴─────────┐
                    │                   │
                    ▼                   ▼
                  OPEN               OBSTACLES
                    │                   │
                    ▼                   ▼
                  Gyro               Pixy2.1
```

This architecture keeps the robot electrically understandable and minimizes the number of changes required between competition rounds.

---

# 3.23 Reproducibility Checklist

Before considering the wiring reproduced correctly, verify:

| Item | Required State |
| :--- | :--- |
| Battery | EV3 Rechargeable DC Battery 45501 installed |
| Port A | Large propulsion motor |
| Port B | Medium steering motor |
| Ports C/D | Not required |
| S2 | Left lateral ultrasonic |
| S3 | Right lateral ultrasonic |
| S4 | Downward Color Sensor |
| S4 casing | Installed and secure |
| Open S1 | EV3 Gyro |
| Obstacle S1 | Pixy2.1 |
| Gyro + Pixy simultaneously | No |
| Pixy connection | Current direct S1 cable |
| Pixy casing | Current 3D-printed casing installed |
| Front ultrasonic | Not part of current architecture |
| HuskyLens | Legacy only |
| Arduino Nano | Legacy only |
| External battery | Not part of current architecture |
| Software mapping | Matches physical ports |

A failure in any of these mappings should be corrected before autonomous calibration begins.

---

# 3.24 Final Engineering Assessment

Piolín's current wiring architecture was designed to make two different autonomous configurations possible while changing as little hardware as practical.

The permanent electrical structure is:

```text
A  → propulsion

B  → steering

S2 → left ultrasonic

S3 → right ultrasonic

S4 → Color Sensor
```

while S1 is the only round-specific sensor connection:

```text
OPEN
→ EV3 Gyro Sensor
```

```text
OBSTACLES
→ Pixy2.1
```

The direct Pixy2.1 connection replaces earlier multi-device vision architectures involving HuskyLens and Arduino Nano. This reduces wiring complexity and keeps the active visual communication path closer to:

```text
Pixy2.1
→ EV3
```

instead of:

```text
camera
→ intermediate controller
→ communication bridge
→ EV3
```

The current Pixy2.1 also includes its **3D-printed casing**, which is treated as part of the camera's physical installation even though it does not require an additional electrical connection.

Likewise, the Color Sensor casing forms part of the calibrated S4 installation.

The most important reproducibility rule is therefore:

> **The electrical connection, physical sensor identity, software port mapping, and mechanical sensor installation must all describe the same architecture.**

Correct wiring is not only a matter of placing a cable into a numbered EV3 port. It establishes the physical assumptions on which the entire navigation software depends.

By keeping the permanent ports fixed and making only S1 modular, PiolínTech reduces wiring errors, simplifies round conversion, and makes the current V4 architecture substantially easier to reproduce and diagnose.

---

<div align="center">

### [← Back to PiolínTech Main README](../../README.md)

</div>

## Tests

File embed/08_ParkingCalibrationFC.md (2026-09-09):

# Piolín Parking Calibration Flowchart

This flowchart represents PiolínTech's **parking calibration process** for the WRO Future Engineers Obstacle Challenge.

Parking calibration is performed progressively.

The objective is not:

```text
change several values
→ run complete parking
→ keep changing numbers
```

Instead, PiolínTech calibrates one physical stage at a time:

```text
VERIFY HARDWARE
      ↓
VERIFY SENSORS
      ↓
CALIBRATE VISION
      ↓
CALIBRATE APPROACH
      ↓
CALIBRATE ENTRY
      ↓
FREEZE ENTRY
      ↓
CALIBRATE ALIGNMENT
      ↓
FREEZE ALIGNMENT
      ↓
CALIBRATE FINAL POSITION
      ↓
VALIDATE STOP
      ↓
REPEAT
      ↓
SAVE BASELINE
```

---

## Parking Calibration Flowchart

```mermaid
flowchart TD

    START([START PARKING CALIBRATION])

    FREEZE["Freeze physical configuration<br/><br/>Pixy mount<br/>Pixy casing<br/>S2/S3 position<br/>Steering linkage<br/>Wheel configuration"]

    HARDWARE{"Hardware configuration<br/>unchanged and secure?"}

    FIX_HW["Correct mechanical / mounting issue<br/>before software tuning"]

    SENSOR_TEST["Verify sensor identities<br/><br/>S1 = Pixy2.1<br/>S2 = LEFT US<br/>S3 = RIGHT US<br/>S4 = Color"]

    SENSOR_OK{"Sensor readings<br/>correct?"}

    FIX_SENSOR["Correct wiring / mapping / mounting"]

    STEER_TEST["Verify Motor B<br/>center and steering direction"]

    STEER_OK{"Steering behavior<br/>repeatable?"}

    FIX_STEER["Correct steering center<br/>or mechanical issue"]

    PIXY_TEST["Test Pink sig1<br/><br/>Record x<br/>y<br/>width<br/>height"]

    PIXY_OK{"Pink detection<br/>stable enough?"}

    PIXY_TUNE["Adjust Pixy signature / mounting /<br/>physical sensing conditions"]

    CONFIRM_TUNE["Calibrate Pink confirmation<br/>and target-lock behavior"]

    APPROACH_SETUP["Define repeatable<br/>parking starting pose"]

    APPROACH_TEST["Run APPROACH only"]

    APPROACH_OK{"Entry condition<br/>repeatable?"}

    TUNE_APPROACH["Tune one approach variable<br/><br/>Speed<br/>visual condition<br/>transition threshold"]

    FREEZE_APPROACH["Freeze successful<br/>APPROACH configuration"]

    ENTRY_TEST["Run ENTRY only<br/>from known-good approach"]

    ENTRY_OK{"Useful parking<br/>entry achieved?"}

    ENTRY_DIAG{"Main entry problem?"}

    ENTRY_STEER["Tune entry steering"]

    ENTRY_PROGRESS["Tune Motor A<br/>entry progression"]

    ENTRY_SPEED["Tune entry speed"]

    FREEZE_ENTRY["Freeze successful<br/>ENTRY configuration"]

    ALIGN_TEST["Run ALIGN from<br/>known-good entry"]

    ALIGN_OK{"Orientation and lateral<br/>geometry acceptable?"}

    ALIGN_DIAG{"Main alignment<br/>problem?"}

    ALIGN_STEER["Tune countersteering"]

    ALIGN_PROGRESS["Tune alignment progression"]

    ALIGN_SPEED["Tune alignment speed"]

    FREEZE_ALIGN["Freeze successful<br/>ALIGN configuration"]

    MEASURE_GEOM["Measure successful parked poses<br/><br/>S2 LEFT<br/>S3 RIGHT<br/>Motor B angle"]

    GEOM_REPEAT{"Measurements form a<br/>repeatable acceptable range?"}

    MORE_GEOM["Collect more successful<br/>geometry samples"]

    SET_TARGETS["Define measured parking<br/>targets and tolerances"]

    FINAL_TEST["Calibrate FINAL movement<br/><br/>Store Motor A reference<br/>Test encoder progression"]

    FINAL_OK{"Final longitudinal<br/>position acceptable?"}

    FINAL_SHORT["Increase / adjust final progression"]

    FINAL_LONG["Reduce progression / speed"]

    STOP_TEST["Test final STOP condition"]

    STOP_OK{"STOP reached correctly<br/>and remains terminal?"}

    FIX_STOP["Tune final geometry conditions<br/>or terminal-state logic"]

    COMPLETE["Run complete parking sequence<br/><br/>Pink → Approach → Entry<br/>→ Align → Final → STOP"]

    REPEATABLE{"Complete parking<br/>repeatable?"}

    FIRST_FAIL["Identify first incorrect phase"]

    ROUTE{"Which phase<br/>failed first?"}

    BACK_APPROACH["Return to APPROACH calibration"]

    BACK_ENTRY["Return to ENTRY calibration"]

    BACK_ALIGN["Return to ALIGN calibration"]

    BACK_FINAL["Return to FINAL / STOP calibration"]

    SAVE["Save known-good parking baseline<br/><br/>Software version<br/>Parameters<br/>Hardware configuration<br/>Test notes"]

    FULL_RUN["Validate from complete<br/>competition-style course"]

    FULL_OK{"Parking still works<br/>after full-course approach?"}

    ENTRY_POSE["Compare parking entry pose<br/>with controlled baseline"]

    VALIDATED([CALIBRATION BASELINE VALIDATED])

    START --> FREEZE
    FREEZE --> HARDWARE

    HARDWARE -- "NO" --> FIX_HW
    FIX_HW --> FREEZE

    HARDWARE -- "YES" --> SENSOR_TEST

    SENSOR_TEST --> SENSOR_OK

    SENSOR_OK -- "NO" --> FIX_SENSOR
    FIX_SENSOR --> SENSOR_TEST

    SENSOR_OK -- "YES" --> STEER_TEST

    STEER_TEST --> STEER_OK

    STEER_OK -- "NO" --> FIX_STEER
    FIX_STEER --> STEER_TEST

    STEER_OK -- "YES" --> PIXY_TEST

    PIXY_TEST --> PIXY_OK

    PIXY_OK -- "NO" --> PIXY_TUNE
    PIXY_TUNE --> PIXY_TEST

    PIXY_OK -- "YES" --> CONFIRM_TUNE

    CONFIRM_TUNE --> APPROACH_SETUP
    APPROACH_SETUP --> APPROACH_TEST

    APPROACH_TEST --> APPROACH_OK

    APPROACH_OK -- "NO" --> TUNE_APPROACH
    TUNE_APPROACH --> APPROACH_TEST

    APPROACH_OK -- "YES" --> FREEZE_APPROACH

    FREEZE_APPROACH --> ENTRY_TEST
    ENTRY_TEST --> ENTRY_OK

    ENTRY_OK -- "NO" --> ENTRY_DIAG

    ENTRY_DIAG -- "Curvature" --> ENTRY_STEER
    ENTRY_DIAG -- "Travel" --> ENTRY_PROGRESS
    ENTRY_DIAG -- "Control margin" --> ENTRY_SPEED

    ENTRY_STEER --> ENTRY_TEST
    ENTRY_PROGRESS --> ENTRY_TEST
    ENTRY_SPEED --> ENTRY_TEST

    ENTRY_OK -- "YES" --> FREEZE_ENTRY

    FREEZE_ENTRY --> ALIGN_TEST
    ALIGN_TEST --> ALIGN_OK

    ALIGN_OK -- "NO" --> ALIGN_DIAG

    ALIGN_DIAG -- "Orientation" --> ALIGN_STEER
    ALIGN_DIAG -- "Travel" --> ALIGN_PROGRESS
    ALIGN_DIAG -- "Control margin" --> ALIGN_SPEED

    ALIGN_STEER --> ALIGN_TEST
    ALIGN_PROGRESS --> ALIGN_TEST
    ALIGN_SPEED --> ALIGN_TEST

    ALIGN_OK -- "YES" --> FREEZE_ALIGN

    FREEZE_ALIGN --> MEASURE_GEOM
    MEASURE_GEOM --> GEOM_REPEAT

    GEOM_REPEAT -- "NO" --> MORE_GEOM
    MORE_GEOM --> MEASURE_GEOM

    GEOM_REPEAT -- "YES" --> SET_TARGETS

    SET_TARGETS --> FINAL_TEST
    FINAL_TEST --> FINAL_OK

    FINAL_OK -- "Too short" --> FINAL_SHORT
    FINAL_SHORT --> FINAL_TEST

    FINAL_OK -- "Overshoot" --> FINAL_LONG
    FINAL_LONG --> FINAL_TEST

    FINAL_OK -- "YES" --> STOP_TEST

    STOP_TEST --> STOP_OK

    STOP_OK -- "NO" --> FIX_STOP
    FIX_STOP --> STOP_TEST

    STOP_OK -- "YES" --> COMPLETE

    COMPLETE --> REPEATABLE

    REPEATABLE -- "NO" --> FIRST_FAIL
    FIRST_FAIL --> ROUTE

    ROUTE -- "APPROACH" --> BACK_APPROACH
    ROUTE -- "ENTRY" --> BACK_ENTRY
    ROUTE -- "ALIGN" --> BACK_ALIGN
    ROUTE -- "FINAL / STOP" --> BACK_FINAL

    BACK_APPROACH --> APPROACH_TEST
    BACK_ENTRY --> ENTRY_TEST
    BACK_ALIGN --> ALIGN_TEST
    BACK_FINAL --> FINAL_TEST

    REPEATABLE -- "YES" --> SAVE

    SAVE --> FULL_RUN
    FULL_RUN --> FULL_OK

    FULL_OK -- "NO" --> ENTRY_POSE
    ENTRY_POSE --> FIRST_FAIL

    FULL_OK -- "YES" --> VALIDATED
```

---

## Calibration Philosophy

Parking calibration should follow:

```text
ONE PHASE
→ ONE PRIMARY VARIABLE
→ REPEAT
→ COMPARE
```

rather than:

```text
change steering

change speed

change Pixy threshold

change encoder distance

change alignment

all at once
```

If several variables are changed simultaneously, PiolínTech cannot determine which change caused the improvement or failure.

---

## 1. Freeze the Hardware

The physical robot should be stable before calibration begins.

The relevant configuration includes:

```text
Pixy2.1 mounting

Pixy2.1 3D-printed casing

S2 LEFT position

S3 RIGHT position

Motor B steering linkage

rear drivetrain

wheel configuration
```

Changing the physical installation can change previously calibrated software behavior.

For example:

```text
Pixy moved
→ x / y / apparent size change
```

or:

```text
steering linkage changed
→ same Motor B command produces different arc
```

Therefore:

> **Mechanical stability comes before numerical tuning.**

---

## 2. Verify Sensor Identity

Before testing parking:

```text
S1 = Pixy2.1

S2 = LEFT

S3 = RIGHT

S4 = Color Sensor
```

The ultrasonic test is simple:

```text
object near LEFT
→ S2 decreases
```

```text
object near RIGHT
→ S3 decreases
```

If this mapping is incorrect, later parking corrections can be reversed even if the parking equations are correct.

---

## 3. Verify Steering

Motor B should be tested before entry calibration.

The team should verify:

```text
steering center

left command

right command

return to center

repeatability
```

If steering behavior changes mechanically, parking trajectory calibration becomes invalid.

---

## 4. Calibrate Pink Detection

The parking reference is:

```text
Pixy sig1
→ Pink
```

Before using Pink for motion, record real camera observations from representative positions.

Useful values are:

```text
x

y

width

height
```

Test from:

```text
far

medium

near

slightly left

slightly right
```

The purpose is to understand what the actual installed Pixy2.1 sees.

---

## 5. Calibrate Pink Confirmation

A parking target should not be accepted from one unstable observation.

Conceptually:

```text
Pink candidate
      ↓
repeat observation
      ↓
confirmation
      ↓
lock
```

Too little confirmation can create:

```text
false parking activation
```

Too much confirmation can create:

```text
late parking entry
```

The correct value should be tested at the actual approach speed.

---

## 6. Establish a Repeatable Approach

Before calibrating the entry arc, Piolín should reach approximately the same starting condition.

The approach test should record:

```text
Pink x

Pink width

Pink height

S2

S3

Motor B angle
```

at:

```text
APPROACH
→ ENTRY
```

If the entry starts from a different pose every time, no fixed steering or encoder value can be evaluated fairly.

---

## 7. Entry Calibration

The main entry variables are:

```text
ENTRY STEERING

ENTRY SPEED

ENTRY PROGRESSION
```

They should be separated during testing.

### Curvature problem

If Piolín follows the wrong arc:

```text
adjust steering
```

### Travel problem

If the arc shape is useful but stops too early or too late:

```text
adjust Motor A progression
```

### Control-margin problem

If the path varies because Piolín moves too quickly:

```text
adjust speed
```

The first incorrect physical characteristic should determine which variable changes.

---

## 8. Freeze the Entry

Once entry becomes repeatable:

```text
DO NOT keep changing it
```

while alignment is being calibrated.

The successful entry becomes the new controlled starting condition.

```text
known-good approach
+
known-good entry
→ alignment calibration
```

This prevents alignment tuning from compensating for a broken entry.

---

## 9. Alignment Calibration

Alignment is responsible for improving orientation after the main parking arc.

The main variables are:

```text
countersteering strength

alignment progression

alignment speed

steering release
```

The desired result is:

```text
acceptable lateral position
+
acceptable chassis orientation
```

not merely:

```text
robot moved farther into parking
```

---

## 10. Measure Successful Geometry

Once acceptable parked poses can be produced, PiolínTech should measure them.

For each successful pose, record:

```text
S2 LEFT

S3 RIGHT

Motor B angle
```

The purpose is to discover:

```text
what successful parking actually looks like
to Piolín's sensors
```

rather than inventing target values before testing.

---

## 11. Define Tolerances from Measurements

Final parking should normally use a region:

```text
TARGET ± TOLERANCE
```

rather than:

```text
measurement == exact value
```

because real robotic behavior contains variation.

Conceptually:

```python
left_ok = (
    abs(left_mm - LEFT_TARGET)
    <= LEFT_TOLERANCE
)
```

The values for:

```text
LEFT_TARGET

RIGHT_TARGET

TOLERANCES
```

should come from measured successful poses.

---

## 12. Final Encoder Calibration

Once:

```text
APPROACH

ENTRY

ALIGN
```

are repeatable, the final longitudinal movement can be calibrated.

Motor A provides:

```text
encoder progression
```

which is stronger physical evidence than time alone.

A current development prototype contains:

```text
PARK_EXTRA_DEG = 300
```

but this remains a prototype value.

The final encoder travel should be determined experimentally from the actual parking geometry.

---

## 13. Final Speed

Final speed affects stopping accuracy.

Higher speed can create:

```text
more movement before complete stop

greater endpoint variation
```

while lower speed can provide:

```text
greater positioning control
```

at the cost of time.

Final speed should therefore be calibrated together with final encoder progression.

---

## 14. STOP Calibration

The final `STOP` condition can combine:

```text
encoder progression

S2 geometry

S3 geometry

Motor B steering state
```

rather than depending on one variable alone.

Conceptually:

```text
encoder valid
+
left geometry valid
+
right geometry valid
+
steering acceptable
→ STOP
```

The exact final conditions remain calibration parameters.

---

## 15. Repeatability Test

A parameter should not become part of the known-good configuration because it worked once.

The complete parking sequence should be repeated:

```text
APPROACH
→ ENTRY
→ ALIGN
→ FINAL
→ STOP
```

If results vary, PiolínTech should identify:

```text
the FIRST phase that becomes inconsistent
```

and return to that calibration stage.

---

## 16. Why the First Failure Matters

Suppose the final parking position is too far left.

Possible causes include:

```text
approach started too far left

entry curvature was too strong

entry lasted too long

alignment was too weak

final movement was incorrect
```

Changing only:

```text
final encoder travel
```

may hide the real cause.

The calibration process therefore follows:

```text
observe final failure
      ↓
review earlier phases
      ↓
identify first incorrect phase
      ↓
change that phase
```

---

## 17. Save a Known-Good Baseline

Once parking becomes repeatable, record:

```text
software version / Git commit

hardware configuration

Pixy installation

approach values

entry values

alignment values

final encoder value

parking tolerances

test results
```

This creates a known-good baseline.

Future experiments should begin from this reference rather than from an unknown combination of values.

---

## 18. Full-Course Validation

A parking configuration that works from a manually controlled starting pose is not automatically validated for competition.

The final test must be:

```text
full autonomous course
      ↓
course progression complete
      ↓
Pink acquisition
      ↓
APPROACH
      ↓
ENTRY
      ↓
ALIGN
      ↓
FINAL
      ↓
STOP
```

If parking fails only after a full course, compare:

```text
actual parking entry pose
```

with:

```text
controlled calibration entry pose
```

before changing parking parameters.

The problem may originate from:

```text
previous corner

pillar recovery

wall positioning
```

rather than parking itself.

---

## Complete Calibration Sequence

```text
                    FREEZE HARDWARE
                           │
                           ▼
                    VERIFY SENSORS
                           │
                           ▼
                    VERIFY STEERING
                           │
                           ▼
                     VERIFY PIXY
                           │
                           ▼
                   CALIBRATE PINK
                           │
                           ▼
               REPEATABLE APPROACH?
                     /          \
                   NO            YES
                   │              │
                   ▼              ▼
              tune approach   FREEZE APPROACH
                                  │
                                  ▼
                          ENTRY REPEATABLE?
                             /          \
                           NO            YES
                           │              │
                           ▼              ▼
                      tune entry      FREEZE ENTRY
                                          │
                                          ▼
                              ALIGNMENT REPEATABLE?
                                  /             \
                                NO               YES
                                │                 │
                                ▼                 ▼
                           tune alignment   FREEZE ALIGNMENT
                                                  │
                                                  ▼
                                      MEASURE SUCCESSFUL POSES
                                                  │
                                                  ▼
                                       DEFINE TOLERANCES
                                                  │
                                                  ▼
                                      CALIBRATE FINAL TRAVEL
                                                  │
                                                  ▼
                                          CALIBRATE STOP
                                                  │
                                                  ▼
                                     COMPLETE PARKING TEST
                                                  │
                                           repeatable?
                                           /      \
                                         NO        YES
                                         │          │
                                         ▼          ▼
                                  find first     SAVE
                                  bad phase     BASELINE
                                                    │
                                                    ▼
                                            FULL COURSE TEST
                                                    │
                                               successful?
                                                /       \
                                              NO         YES
                                              │           │
                                              ▼           ▼
                                      inspect entry    VALIDATED
                                           pose
```

---

## Final Calibration Principle

The complete process follows one rule:

> **PiolínTech calibrates parking from the beginning of the maneuver toward the end. A later phase should only be tuned after the previous phase has become sufficiently repeatable, and a configuration becomes a baseline only after repeated physical testing confirms that the result can be reproduced.**

This prevents:

```text
final movement
```

from compensating for:

```text
bad alignment
```

prevents:

```text
alignment
```

from compensating for:

```text
bad entry
```

and prevents:

```text
entry
```

from compensating for:

```text
an inconsistent approach
```

The resulting calibration chain is therefore:

```text
HARDWARE
→ SENSORS
→ VISION
→ APPROACH
→ ENTRY
→ ALIGNMENT
→ FINAL POSITION
→ STOP
→ REPEATABILITY
→ BASELINE
```

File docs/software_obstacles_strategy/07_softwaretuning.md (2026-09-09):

# 7. Software Tuning

<div align="center">

Piolín in its current Obstacle Challenge configuration

<br>

<sub><b>Figure 7.1.</b> Software tuning on Piolín is performed on the complete physical robot because steering, speed, vision, wall geometry, and state transitions interact dynamically.</sub>

</div>

Software tuning is the process of converting Piolín's control architecture into reliable physical behavior.

The objective is not to search randomly for a combination of numbers that produces one successful run.

Instead, tuning should answer:

```text
What behavior is failing?

Which software layer controls that behavior?

Which parameter has a physical relationship to the failure?

What changes when that parameter is modified?

Does the improvement repeat?
```

The current Obstacle Challenge controller is still under development, so several parameters remain experimental.

The main tuning areas include:

```text
Pixy target confirmation

target relevance

target locking

obstacle steering strength

visual steering influence

drive speed

wall-controller authority

wall safety

pillar-pass confirmation

post-pillar recovery

corner interaction

parking
```

These values should be calibrated progressively and should not be treated as final specifications until repeated tests support them.

---

## 7.1 Tune the System in the Correct Order

Piolín should not begin software tuning until the physical system is sufficiently repeatable.

The recommended order is:

```text
MECHANICS
    ↓
RAW SENSORS
    ↓
STEERING RESPONSE
    ↓
NORMAL DRIVING
    ↓
VISION DETECTION
    ↓
TARGET SELECTION
    ↓
PILLAR AVOIDANCE
    ↓
PASS CONFIRMATION
    ↓
RECOVERY
    ↓
CORNER INTERACTION
    ↓
PARKING
```

If the steering mechanism is physically misaligned, changing Pixy parameters will not solve the problem.

Likewise, if the camera reports the wrong signature, increasing obstacle steering strength will only make the incorrect decision happen more aggressively.

The general rule is:

> **Tune the earliest incorrect layer first.**

---

# 7.2 Separate Parameters by Responsibility

One of the most important software practices is keeping constants grouped by the physical behavior they influence.

A clean controller can conceptually organize parameters as:

```python
# ------------------------------------------------------------
# DRIVE
# ------------------------------------------------------------

NORMAL_SPEED = ...
AVOID_SPEED = ...
RECOVERY_SPEED = ...

# ------------------------------------------------------------
# STEERING
# ------------------------------------------------------------

MAX_STEER = ...
TARGET_STEP = ...
STEER_TOLERANCE = ...

# ------------------------------------------------------------
# ULTRASONIC / WALL
# ------------------------------------------------------------

WALL_TARGET = ...
WALL_SOFT = ...
WALL_CRITICAL = ...

# ------------------------------------------------------------
# PIXY
# ------------------------------------------------------------

TARGET_CONFIRMATIONS = ...
MIN_TARGET_RELEVANCE = ...
TARGET_LOSS_LIMIT = ...

# ------------------------------------------------------------
# OBSTACLE
# ------------------------------------------------------------

RED_BIAS = ...
GREEN_BIAS = ...
VISUAL_GAIN = ...

# ------------------------------------------------------------
# RECOVERY
# ------------------------------------------------------------

RECOVERY_GAIN = ...
RECOVERY_RELEASE = ...
```

The exact variable names may change in the final program.

The important architectural principle is that a reader should immediately understand whether a value changes:

```text
perception

trajectory

safety

speed

recovery
```

rather than searching through the entire source file.

---

# 7.3 Bound Every Strong Controller

Piolín's current prototype already uses a common utility:

```python
def clamp(value, minimum, maximum):
    if value < minimum:
        return minimum

    if value > maximum:
        return maximum

    return value
```

This pattern is important during tuning because proportional or nonlinear calculations can otherwise produce unexpectedly large commands.

For example:

```python
visual_term = gain * visual_error

visual_term = clamp(
    visual_term,
    -VISUAL_LIMIT,
    VISUAL_LIMIT
)
```

The same concept applies to:

```text
wall correction

obstacle steering

recovery steering

speed reduction
```

A gain should control sensitivity.

A limit should control the maximum authority available to that controller.

These are separate tuning responsibilities.

For example:

```text
high gain + low limit
```

creates a controller that reaches its maximum quickly.

```text
lower gain + higher limit
```

creates a controller that reacts progressively but can eventually become stronger.

Tuning should therefore consider both.

---

# 7.4 Tune Steering Response Before Obstacle Logic

<div align="center">

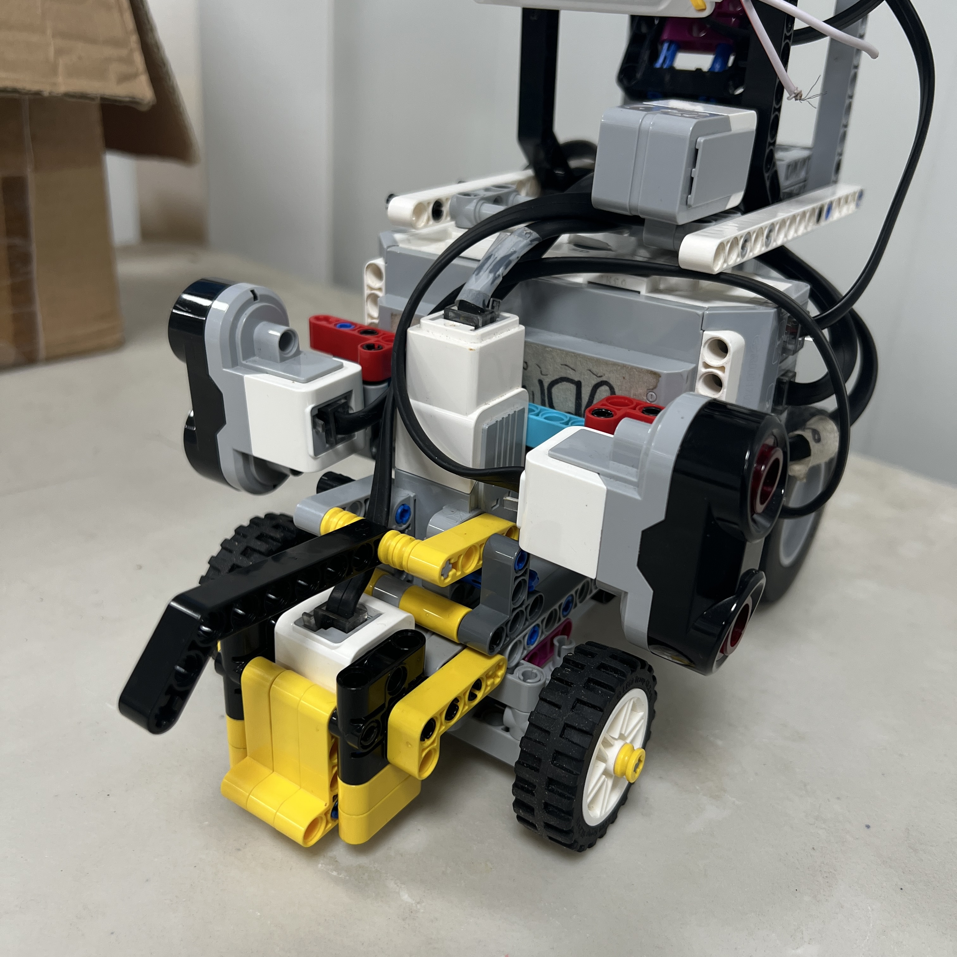
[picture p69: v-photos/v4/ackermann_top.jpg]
Piolín Ackermann-style steering system


<br>

<sub><b>Figure 7.2.</b> Software steering values must be tuned against the physical response of Piolín's Ackermann-style steering mechanism.</sub>

</div>

Motor B commands do not directly represent vehicle curvature.

The complete chain is:

```text
software steering target
      ↓
Motor B angle
      ↓
steering linkage
      ↓
front-wheel angles
      ↓
vehicle curvature
```

Therefore the first steering-related questions should be:

```text
Is steering center repeatable?

Does positive steering move the expected direction?

Does negative steering move the opposite direction?

Can Motor B reach its target quickly enough?

Does the linkage bind near the limits?
```

Only after this is confirmed should obstacle steering magnitude be tuned.

Otherwise a navigation problem can actually be an actuator problem.

---

# 7.5 Steering Target Smoothing

The current Piolín prototype limits how much the steering target can change in one control cycle:

```python
def smooth_target(target):
    global current_target

    diff = target - current_target

    diff = clamp(
        diff,
        -TARGET_STEP,
        TARGET_STEP
    )

    current_target += diff

    return current_target
```

This parameter is especially important during obstacle avoidance.

### `TARGET_STEP` too large

Possible behavior:

```text
abrupt steering

overshoot

rapid left/right changes

camera movement becomes aggressive

mechanical shock
```

### `TARGET_STEP` too small

Possible behavior:

```text
slow steering response

late pillar avoidance

wide trajectory

wall collision before steering reaches requested value
```

The correct setting balances:

```text
smoothness
```

against:

```text
reaction speed
```

It should be tested using the same representative Motor A speed intended for the maneuver.

---

# 7.6 Tune Speed Together with Steering

Drive speed and steering cannot be calibrated independently.

Suppose Motor B requires a short physical time to move from:

```text
center
```

to:

```text
strong right
```

At low Motor A speed, Piolín travels only a short distance during that steering response.

At high speed:

```text
same Motor B response time
→ much greater physical travel
```

This can make a previously successful obstacle maneuver begin too late.

The current prototype already treats speed as state-dependent:

```python
if wall_active:
    drive.run(wall_speed)

elif acquire_progress < 1.0:
    drive.run(ACQUIRE_SPEED)

elif abs(combined_offset) >= TURN_STEER_THRESHOLD:
    drive.run(TURN_SPEED)

else:
    drive.run(DRIVE_SPEED)
```

The final Obstacle controller can follow the same principle:

```text
NORMAL
→ normal speed

TARGET_ACQUIRE
→ controlled approach speed

AVOID
→ obstacle speed

RECOVER
→ recovery speed

CRITICAL WALL
→ reduced safety speed
```

If avoidance is consistently late, the first solution should not always be:

```text
increase steering
```

It may be better to reduce the approach or maneuver speed.

---

# 7.7 Tune Pixy Detection Before Pixy Steering

<div align="center">

Pixy2.1 red pillar detection during tuning

<br>

<sub><b>Figure 7.3.</b> Vision detection and steering response should be tuned as separate stages.</sub>

</div>

Before changing obstacle steering values, verify:

```text
Red → sig2

Green → sig3

Pink → sig1
```

Then confirm:

```text
target coordinates behave plausibly

block size changes with approach

target remains visible under representative lighting

camera mounting remains unchanged
```

The current Pixy2.1 should be tested with its **3D-printed casing installed**, because the casing is part of the physical camera configuration.

The tuning sequence should be:

```text
CAMERA DETECTS CORRECTLY
        ↓
TARGET SELECTS CORRECTLY
        ↓
PASS SIDE SELECTS CORRECTLY
        ↓
THEN tune steering
```

If the camera reports:

```text
RED
```

and the state machine correctly reports:

```text
PASS RIGHT
```

then changing camera thresholds will not fix a physical left turn.

The problem is downstream.

---

# 7.8 Target Confirmation and Reaction Delay

The current color-event prototype already demonstrates the concept of confirmation before action:

```python
if detected == candidate_color:
    candidate_count += 1
else:
    candidate_color = detected
    candidate_count = 1
```

followed by:

```python
if candidate_count >= COLOR_CONFIRMATIONS:
```

Pixy target confirmation can use the same architecture.

This creates an important tuning trade-off.

### Too few confirmations

```text
fast reaction
+
higher chance of reacting to unstable detection
```

### Too many confirmations

```text
stable classification
+
later physical reaction
```

The confirmation count should therefore be evaluated dynamically.

A useful test is:

```text
same pillar

same starting position

same speed

repeat several trials
```

and record:

```text
first visible detection

confirmed detection

physical steering start

pillar clearance
```

The correct confirmation setting is the lowest value that remains sufficiently stable under representative conditions.

---

# 7.9 Tune Target Relevance

One of the main goals of relevance tuning is preventing distant pillars from controlling steering too early.

The desired behavior is:

```text
pillar visible far ahead
→ recognized
→ little steering authority
```

then:

```text
pillar becomes relevant
→ controller prepares
```

and finally:

```text
pillar close enough
→ avoidance gains strong authority
```

Potential relevance inputs include:

```text
width

height

x

y

current state

previous target
```

The final formula should be tuned using repeated scenarios.

For example:

| Test | Near Object | Far Object | Correct Target |
| :--- | :--- | :--- | :--- |
| 1 | Red | Green | — |
| 2 | Green | Red | — |
| 3 | Red | Red | — |
| 4 | Green | Green | — |
| 5 | Red center | Green peripheral | — |

The goal is not to create the mathematically most complicated scoring function.

It is to create the simplest function that consistently selects the physically relevant pillar.

---

# 7.10 Tune Obstacle Steering in Isolation

<div align="center">

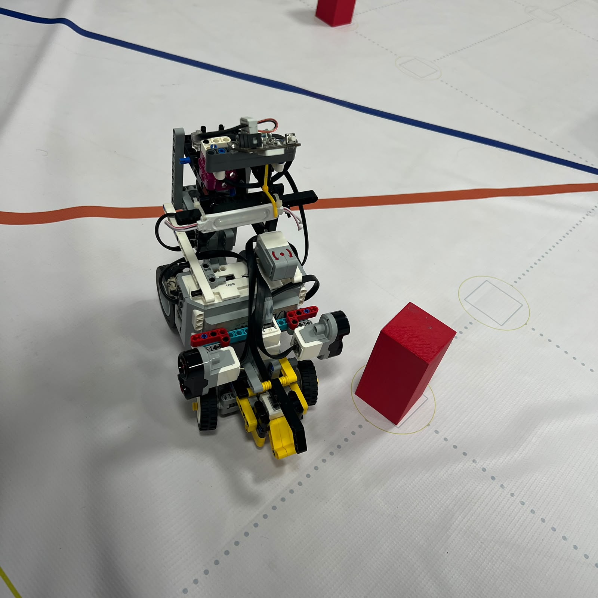
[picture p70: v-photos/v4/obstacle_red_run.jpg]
Piolín Red obstacle maneuver used for software tuning


<br>

<sub><b>Figure 7.4.</b> Red and Green avoidance should first be tuned as isolated maneuvers before consecutive-pillar or full-course testing.</sub>

</div>

Obstacle steering should first be tested with one pillar.

Start with:

```text
one Red pillar
```

until Piolín can consistently attempt:

```text
PASS RIGHT
```

Then test:

```text
one Green pillar
```

for:

```text
PASS LEFT
```

Tune behaviors such as:

```text
when avoidance begins

initial steering bias

maximum steering authority

visual correction influence

avoidance speed
```

without simultaneously changing recovery.

A useful development rule is:

```text
first make the PASS correct

then make the RECOVERY correct
```

If Piolín passes the pillar successfully but hits the wall afterward, do not weaken the pass until recovery has been investigated.

---

# 7.11 Red and Green Do Not Need Identical Numbers

<div align="center">

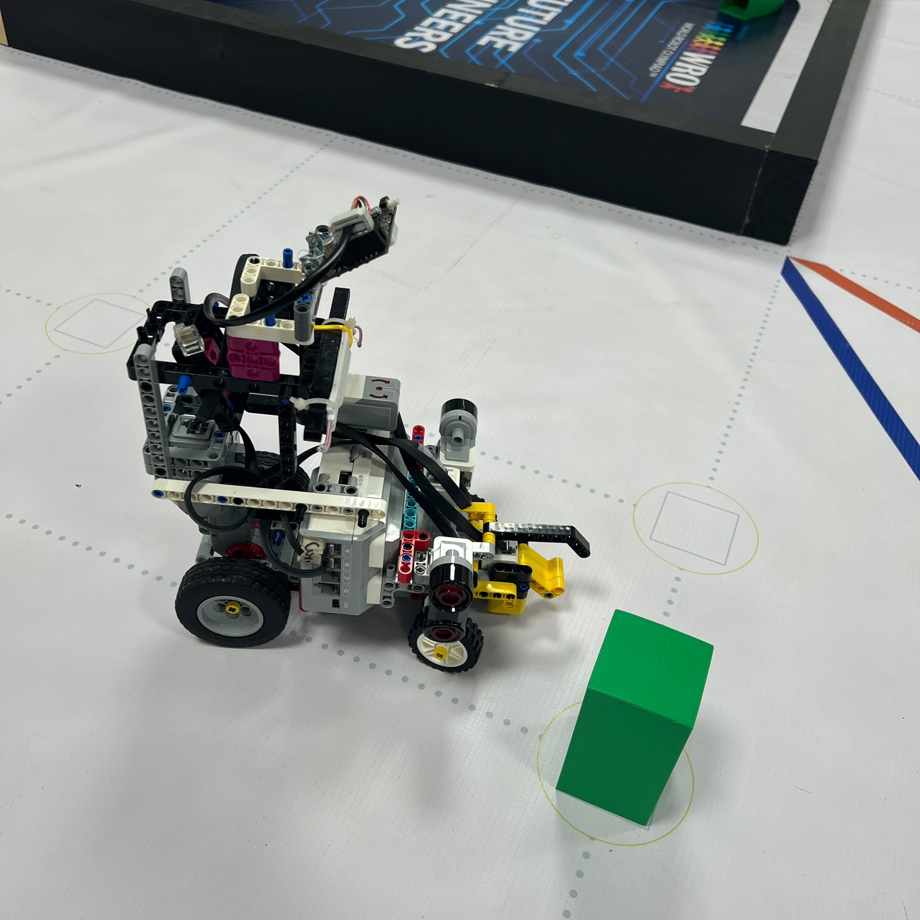
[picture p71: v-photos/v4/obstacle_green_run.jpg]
Piolín Green obstacle maneuver used for software tuning


<br>

<sub><b>Figure 7.5.</b> The logical Red and Green rules are symmetrical, but the physical steering mechanism may require slightly different calibrated values.</sub>

</div>

The competition rules are perfectly clear:

```text
RED
→ RIGHT
```

```text
GREEN
→ LEFT
```

However, the physical robot may not have perfectly symmetrical steering behavior.

Possible causes include:

```text
Ackermann linkage geometry

mechanical tolerances

Motor B center

weight distribution

sensor placement
```

Therefore the final software may legitimately use slightly different calibrated magnitudes for Red and Green.

For example, conceptually:

```python
RED_BIAS = ...
GREEN_BIAS = ...
```

This does **not** mean the competition logic is different.

It only means the physical actuator may require different calibration to produce comparable trajectories.

Any asymmetry should be justified by measured testing rather than added without evidence.

---

# 7.12 Tune Wall Authority During AVOID

One of the most important tuning parameters is not necessarily a single number.

It is **controller authority**.

During `NORMAL`:

```text
wall geometry
→ strong authority
```

During `AVOID`:

```text
pillar controller
→ strong authority
```

Normal wall following should therefore be weakened or temporarily suspended as a trajectory controller while the pillar maneuver is active.

Critical wall safety remains available.

This distinction matters because:

```text
Red obstacle controller
→ RIGHT
```

can otherwise be opposed by:

```text
normal centering
→ LEFT
```

creating:

```text
weak steering

zig-zag

late pillar pass

apparent inversion
```

The tuning question should therefore be:

```text
Is obstacle steering too weak?
```

but also:

```text
Is another controller fighting it?
```

Increasing obstacle gains without checking arbitration can hide the true problem.

---

# 7.13 Wall-Safety Tuning

The current prototype contains an independent wall-safety controller:

```python
wall_active, wall_cmd, wall_speed = side_wall_guard(
    left,
    right
)

if wall_active:
    combined_offset = wall_cmd
```

This structure should remain logically separate from normal wall following.

The safety system needs to answer:

```text
When should safety begin influencing the robot?

When should it completely override navigation?

How much should speed decrease?
```

If safety activates too early:

```text
pillar maneuver becomes restricted

robot may fail to reach required side
```

If safety activates too late:

```text
robot has insufficient physical distance to escape wall
```

Therefore safety thresholds should be tuned using controlled wall-approach tests, not only during complete obstacle runs.

---

# 7.14 Tune Pass Confirmation Separately

`PASS_CONFIRM` is one of the most important states to calibrate.

The failure modes are opposite.

### Confirmation too early

```text
pillar still beside vehicle
      ↓
RECOVER begins
      ↓
Piolín turns back toward pillar
```

### Confirmation too late

```text
pillar already cleared
      ↓
AVOID continues
      ↓
Piolín approaches outside wall
```

Useful evidence can include:

```text
last Pixy target position

target disappearance history

S2/S3 changes

vehicle progression

current obstacle side
```

The final pass criterion should be tuned using repeated video and telemetry.

A test table can use:

| Trial | Pillar | Visual Loss | US Change | Recovery Start | Result |
| :---: | :--- | :--- | :--- | :--- | :--- |
| 1 | Red | — | — | — | — |
| 2 | Red | — | — | — | — |
| 3 | Green | — | — | — | — |
| 4 | Green | — | — | — | — |

This helps determine whether recovery consistently begins at the correct physical point.

---

# 7.15 Recovery Tuning

Recovery should be tuned only after the basic pillar pass is working.

The goal is:

```text
pillar cleared
      ↓
countersteer
      ↓
vehicle returns toward useful geometry
      ↓
steering reduces
      ↓
NORMAL resumes
```

Important parameters may include:

```text
initial recovery strength

recovery steering limit

recovery speed

wall geometry influence

release threshold
```

The recovery controller should not simply apply:

```text
avoidance steering × -1
```

because the vehicle is now in a different physical position.

The correct objective is not:

```text
undo previous steering
```

but:

```text
restore useful course geometry
```

---

# 7.16 Tune One Failure at a Time

Suppose a Red maneuver fails.

Possible observations might be:

```text
A. Red not detected.

B. Red detected but target selected late.

C. Target selected correctly but steering begins late.

D. Steering begins correctly but is too weak.

E. Pillar is passed correctly but recovery starts too early.

F. Recovery works but next target is not acquired.
```

Each failure belongs to a different tuning layer.

A poor tuning method would be:

```text
increase camera threshold

increase steering

reduce speed

change wall gain

change recovery
```

all at once.

A stronger method is:

```text
identify first incorrect event
      ↓
change parameter linked to that event
      ↓
repeat same scenario
```

This makes every test produce useful engineering information.

---

# 7.17 Debug Telemetry for Tuning

The current Piolín prototype already prints detailed controller information such as:

```python
print(
    "L:", int(left),
    "R:", int(right),
    "X:", round(x_est, 1),
    "ERR:", round(error, 1),
    "WALL_SAFE:", wall_active,
    "CMD:", round(combined_offset, 1),
    "TARGET:", round(current_target, 1),
    "REAL:", round(steer.angle(), 1)
)
```

Obstacle tuning should extend this idea.

A useful obstacle telemetry record can include:

```text
STATE

TARGET SIG

TARGET X

TARGET WIDTH

TARGET HEIGHT

RELEVANCE

CONFIRMATIONS

LOCK ACTIVE

S2 LEFT

S3 RIGHT

OBSTACLE COMMAND

WALL COMMAND

SAFETY ACTIVE

FINAL COMMAND

REAL STEERING
```

For example:

```text
STATE: AVOID
SIG: 2
PASS: RIGHT
X: ...
W: ...
REL: ...
S2: ...
S3: ...
OBS: RIGHT
SAFE: False
FINAL: RIGHT
REAL: ...
```

Telemetry should make it possible to identify the first incorrect stage without guessing from the final collision.

---

# 7.18 Use Video and Telemetry Together

Some obstacle transitions occur too quickly to judge accurately while watching the run live.

Video can reveal:

```text
when the pillar first entered the FOV

when steering began

when the pillar reached the side of the robot

when the camera lost it

when recovery began

when the next wall became relevant
```

Telemetry can reveal:

```text
what state the software believed it was in

which target was active

which command was requested
```

The strongest debugging combination is:

```text
VIDEO
+
TERMINAL OUTPUT
+
TEST ID
```

For example:

```text
video shows wheels turn left
```

while:

```text
terminal says FINAL: RIGHT
```

This immediately moves investigation toward:

```text
Motor B sign

steering conversion

mechanical response
```

instead of Pixy detection.

---

# 7.19 Maintain a Known-Good Baseline

Tuning should always preserve the most recent stable configuration.

A useful workflow is:

```text
KNOWN-GOOD VERSION
       ↓
create one experimental change
       ↓
test repeatedly
       ↓
compare
```

If better:

```text
document
→ commit
→ new baseline
```

If worse:

```text
reject
→ return to known-good
```

This is much safer than repeatedly editing the same file until several successful behaviors disappear.

Important known-good configurations should be associated with:

```text
Git commit

software file

robot hardware configuration

calibration values

test notes
```

rather than remembered only through filenames.

---
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

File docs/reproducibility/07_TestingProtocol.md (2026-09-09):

# 7. Testing Protocol

<div align="center">

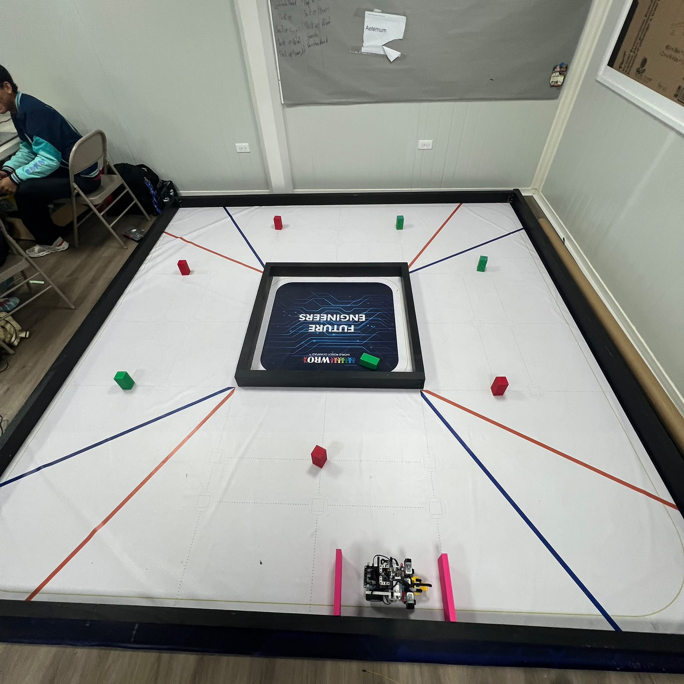
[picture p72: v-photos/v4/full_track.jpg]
Full track used for repeatable Piolín testing


<br>

<sub><b>Figure 7.1.</b> Piolín's testing protocol progresses from isolated subsystem checks to repeated full-track trials under documented conditions.</sub>

</div>

PiolínTech uses a structured testing protocol to evaluate whether a mechanical, sensing, or software modification actually improves the robot.

A successful autonomous run is useful evidence, but **one successful run alone does not demonstrate repeatability**. The purpose of this protocol is to make tests comparable by controlling the most important variables and recording enough information to understand why a result occurred.

The general testing process is:
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

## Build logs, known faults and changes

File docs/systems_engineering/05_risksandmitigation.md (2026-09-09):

# 5. Risks and Mitigation

<div align="center">

Piolín in its current Obstacle Challenge configuration

<br>

<sub><b>Figure 5.1.</b> Piolín is designed as an integrated system in which failures in sensing, mechanics, control, or software can propagate into navigation errors.</sub>

</div>

Autonomous performance depends not only on what Piolín can do when every subsystem behaves correctly, but also on how the system responds when information becomes uncertain, a mechanism behaves differently than expected, or two controllers request conflicting actions.

PiolínTech therefore treats risk management as part of the engineering process.

The basic risk cycle is:

```text
IDENTIFY POSSIBLE FAILURE
        ↓
UNDERSTAND ITS EFFECT
        ↓
DETECT IT AS EARLY AS POSSIBLE
        ↓
REDUCE ITS PROBABILITY
        ↓
LIMIT ITS CONSEQUENCES
        ↓
TEST THE MITIGATION
```

The main risk categories are:

```text
MECHANICAL

SENSING

PERCEPTION

CONTROL

STATE MANAGEMENT

COURSE PROGRESSION

PARKING

POWER / CONNECTIONS

SOFTWARE / CONFIGURATION

TESTING / REPRODUCIBILITY
```

A mitigation is considered stronger when it prevents a failure from propagating into several later subsystems.

For example:

```text
incorrect Pixy block
→ target validation
```

is preferable to allowing the incorrect block to reach:

```text
target selection
→ AVOID
→ steering
→ collision
```

---

## 5.1 Risk Evaluation Method

PiolínTech uses qualitative risk assessment while development measurements are still being collected.

Two properties are considered:

```text
LIKELIHOOD
→ How easily could this occur during realistic operation?
```

and:

```text
IMPACT
→ How severely could it affect the run?
```

The qualitative levels are:

```text
LOW

MEDIUM

HIGH
```

These labels are engineering priorities, not statistically measured probabilities.

A failure can receive high priority even if it is relatively uncommon when its consequence is severe.

For example:

```text
incorrect Red/Green passing side
```

has high impact because it directly violates the required obstacle behavior.

By contrast:

```text
small temporary ultrasonic noise
```

may have low impact if filtering and state logic prevent it from reaching the steering output.

---

## 5.2 Current Risk Register

| ID | Risk | Likelihood | Impact | Primary Mitigation | Status |
| :--- | :--- | :---: | :---: | :--- | :---: |
| `R-01` | Steering center changes or is incorrect | Medium | High | Center verification, Motor B feedback, bounded steering | ACTIVE |
| `R-02` | Mechanical steering play changes trajectory | Medium | High | Mechanical inspection, repeatable mounting, trajectory testing | ACTIVE |
| `R-03` | S2/S3 identity is reversed in software | Low | High | Fixed `S2 = LEFT`, `S3 = RIGHT` convention | MITIGATED |
| `R-04` | Ultrasonic spike creates wrong correction | Medium | Medium | Range validation, short filtering, bounded commands | MITIGATED / TUNING |
| `R-05` | Normal wall control fights pillar avoidance | Medium | High | State-dependent authority and arbitration | ACTIVE |
| `R-06` | Pixy detects wrong or irrelevant target | Medium | High | Signature validation, relevance selection, confirmation | ACTIVE |
| `R-07` | Target changes during active avoidance | Medium | High | Target lock until pass confirmation | ACTIVE |
| `R-08` | Pixy loses pillar during steering | Medium | High | Temporary target memory + lateral context | ACTIVE |
| `R-09` | Red/Green passing side becomes inverted | Low | High | Signature-only rule: Red RIGHT, Green LEFT | MITIGATED |
| `R-10` | Lighting changes vision behavior | Medium | High | Physical casing, signature calibration, repeated testing | ACTIVE |
| `R-11` | S4 counts one floor marking more than once | Medium | High | Confirmation, latch, release, encoder separation | MITIGATED / TUNING |
| `R-12` | Real floor event is missed at speed | Medium | High | Dynamic RGB testing, confirmation tuning | ACTIVE |
| `R-13` | Incorrect state transition activates wrong controller | Medium | High | Explicit states, transition guards, telemetry | ACTIVE |
| `R-14` | Recovery begins before pillar is passed | Medium | High | `PASS_CONFIRM` before `RECOVER` | ACTIVE |
| `R-15` | Recovery begins too late | Medium | High | Visual + ultrasonic pass evidence | ACTIVE |
| `R-16` | Corner geometry is interpreted as wall error | Medium | High | Dedicated `CORNER` state, reduced straight-wall authority | ACTIVE |
| `R-17` | Parking activates before course completion | Low/Medium | High | Course-progress gate before Pink target authority | MITIGATED |
| `R-18` | Parking final movement overshoots | Medium | Medium/High | Encoder progression, lower final speed, geometry check | ACTIVE |
| `R-19` | S1 round configuration does not match software | Low | High | Separate Open/Obstacle configurations and startup checks | ACTIVE |
| `R-20` | Software regression removes previously working behavior | Medium | High | Known-good baselines, isolated changes, Git version control | ACTIVE |

The status column describes the current engineering treatment:

```text
MITIGATED
→ architecture already contains a strong preventive measure

ACTIVE
→ still requires continued physical validation

TUNING
→ mitigation exists but numerical parameters are still being calibrated
```

---

# 5.3 Mechanical and Steering Risks

<div align="center">

Piolín Motor B steering installation

<br>

<sub><b>Figure 5.2.</b> Mechanical steering consistency is a prerequisite for meaningful software calibration.</sub>

</div>

Piolín's Ackermann architecture makes steering repeatability particularly important.

A software command may be correct while the physical result differs because of:

```text
mechanical play

linkage movement

Motor B center drift

wheel support movement

binding near steering limits
```

The risk chain is:

```text
MECHANICAL CHANGE
      ↓
actual wheel angle differs
      ↓
trajectory differs
      ↓
sensor geometry changes
      ↓
controller compensates incorrectly
```

This is dangerous because the visible symptom may appear to be a software problem.

### Mitigation

Before major tuning sessions:

```text
inspect steering linkage

verify Motor B mounting

verify steering center

verify left/right motion

check that the wheels return repeatably
```

Software also limits steering commands rather than allowing unlimited Motor B targets.

The actuator layer uses Motor B feedback so the controller can distinguish:

```text
requested steering
```

from:

```text
actual steering
```

A failure such as:

```text
FINAL CMD: RIGHT

REAL STEER: LEFT
```

can therefore be diagnosed downstream from the perception system.

---

# 5.4 Ultrasonic Sensing Risks

<div align="center">

Piolín ultrasonic sensor mapping

<br>

<sub><b>Figure 5.3.</b> Fixed physical sensor identities reduce the risk of software left/right inversion.</sub>

</div>

The permanent ultrasonic convention is:

```text
S2 = LEFT

S3 = RIGHT
```

One major risk is accidentally reversing these identities inside software.

That could transform:

```text
left wall close
```

into:

```text
software believes right wall close
```

and cause steering directly toward the danger.

### Mapping Mitigation

The physical names remain fixed across:

```text
wiring

code

telemetry

documentation

testing
```

Navigation direction may change logical roles such as:

```text
inner

outer
```

but it must never rename:

```text
LEFT

RIGHT
```

---

Ultrasonic sensors can also produce temporary unusual measurements.

One development controller therefore uses:

```text
range validation
```

followed by:

```text
short median filtering
```

before navigation uses the values.

The mitigation philosophy is:

```text
one strange measurement
≠
one extreme steering command
```

At the same time, filtering cannot become so strong that:

```text
real wall danger
```

is detected too late.

The remaining risk is therefore a trade-off between:

```text
noise rejection
```

and:

```text
reaction speed
```

which continues to require physical tuning.

---

# 5.5 Pixy2.1 Perception Risks

<div align="center">

Piolín Pixy2.1 forward vision sensor

<br>

<sub><b>Figure 5.4.</b> Pixy2.1 provides essential obstacle information, but camera observations require validation before being allowed to control a maneuver.</sub>

</div>

Pixy2.1 is the main forward-perception sensor during Obstacles.

Several risks must be managed:

```text
incorrect signature

small irrelevant color region

distant pillar selected too early

multiple pillars visible

target leaves field of view

lighting changes classification
```

The mitigation architecture therefore separates:

```text
DETECTION
```

from:

```text
TARGET SELECTION
```

from:

```text
STEERING
```

The planned process is:

```text
READ BLOCKS
      ↓
VALIDATE
      ↓
EVALUATE RELEVANCE
      ↓
CONFIRM
      ↓
LOCK
      ↓
AVOID
```

A raw camera block should never directly become a Motor B command.

---

## Multiple-Target Risk

Suppose Pixy sees:

```text
near Red

far Green
```

Using:

```text
first block returned
```

creates the risk of choosing the wrong physical obstacle.

The mitigation is relevance-based selection using information such as:

```text
signature

x

y

width

height

current state

previous target
```

The exact scoring formula remains under development.

---

## Target-Loss Risk

When Piolín turns:

```text
camera rotates
      ↓
pillar moves across image
      ↓
pillar may disappear
```

A missing frame therefore does not prove that the obstacle has been passed.

The mitigation is:

```text
temporary target memory
+
PASS_CONFIRM
+
S2/S3 physical context
```

rather than:

```text
no Pixy block
→ immediately release target
```

---

# 5.6 Risk of Red/Green Direction Inversion

One of the highest-impact obstacle failures is applying the wrong competition rule.

The required mapping is fixed:

```text
sig2
→ RED
→ PASS RIGHT
```

```text
sig3
→ GREEN
→ PASS LEFT
```

A dangerous implementation would derive passing side from:

```text
pillar x-position
```

because the target can appear on either side of the image while Piolín approaches it.

The mitigation is architectural:

```text
SIGNATURE
→ required side
```

```text
IMAGE COORDINATES
→ target geometry
```

These roles are never exchanged.

The software should be able to print explicitly:

```text
SIG: 2
PASS: RIGHT
```

or:

```text
SIG: 3
PASS: LEFT
```

before steering is applied.

This allows the team to determine whether an inverted physical trajectory originates in:

```text
vision mapping
```

or later in:

```text
controller sign

arbitration

Motor B actuation
```

---

# 5.7 Controller-Conflict Risk

One of the most important system-level risks occurs when several individually reasonable controllers request different steering directions.

For example:

```text
RED pillar
→ obstacle controller requests RIGHT
```

while:

```text
normal wall control
→ requests LEFT
```

and:

```text
corner logic
→ requests another trajectory
```

If all commands are simply added:

```text
result can be weak or unstable
```

The mitigation is explicit controller arbitration.

The conceptual hierarchy is:

```text
CRITICAL SAFETY
      ↓
CURRENT COMMITTED MANEUVER
      ↓
NORMAL NAVIGATION
```

Therefore:

```text
NORMAL
→ wall geometry has authority
```

```text
AVOID
→ pillar controller has authority
```

```text
CORNER
→ corner controller has authority
```

```text
PARKING
→ parking controller has authority
```

while critical wall safety remains available where required.

This architecture reduces the risk that a correct obstacle decision appears physically inverted because another controller quietly cancelled it.

---

# 5.8 State-Transition Risks

A state machine reduces controller conflict, but it introduces another risk:

```text
correct controller
+
wrong state
=
wrong behavior
```

Examples include:

```text
RECOVER starts before pillar is passed

CORNER begins from false geometry

PARKING becomes active too early

NORMAL resumes before steering has stabilized
```

The mitigation is to require evidence for transitions.

For example:

```text
TARGET_ACQUIRE
→ confirmed target
→ AVOID
```

rather than:

```text
one detection
→ AVOID
```

and:

```text
AVOID
→ physical pass evidence
→ PASS_CONFIRM
→ RECOVER
```

rather than:

```text
camera loses target
→ RECOVER
```

Likewise:

```text
course progress complete
+
Pink confirmed
→ PARKING
```

rather than:

```text
Pink visible
→ PARKING
```

State transitions should also be exposed in telemetry so an incorrect transition can be identified directly.

---

# 5.9 Corner and Recovery Risks

Corners and post-pillar recovery are especially sensitive because the robot is intentionally leaving one stable geometry and trying to acquire another.

During a corner:

```text
S2/S3 straight-corridor assumptions degrade
```

If normal wall control remains fully active, it may interpret the expected corner geometry as:

```text
large lateral error
```

and steer against the turn.

The mitigation is:

```text
dedicated CORNER state
+
reduced straight-wall authority
+
critical safety still available
```

After a pillar, the opposite transition occurs.

Piolín must return from:

```text
intentional lateral avoidance
```

to:

```text
stable track geometry
```

Two high-impact recovery risks exist.

### Recovery too early

```text
pillar still beside robot
      ↓
countersteer
      ↓
vehicle moves back toward pillar
```

Mitigation:

```text
PASS_CONFIRM before RECOVER
```

### Recovery too late

```text
pillar already cleared
      ↓
avoidance continues
      ↓
outside wall approaches
```

Mitigation:

```text
use Pixy history + lateral ultrasonic evidence
to identify when the target is physically behind the active maneuver
```

The final thresholds remain active tuning parameters.

---

# 5.10 Floor Detection and Course-Counting Risks

<div align="center">

Piolín Color Sensor casing

<br>

<sub><b>Figure 5.5.</b> Physical light control and software event filtering work together to reduce floor-detection risk.</sub>

</div>

A course-progression failure can affect several later states.

For example:

```text
one Blue line counted twice
      ↓
course count becomes incorrect
      ↓
parking eligibility occurs early
```

or:

```text
one event missed
      ↓
count remains low
      ↓
parking never becomes eligible
```

Piolín therefore separates:

```text
RGB / color classification
```

from:

```text
event counting
```

Mitigation includes:

```text
candidate confirmation

event latch

neutral-floor release

minimum encoder separation
```

The goal is:

```text
one physical marking
→ one software event
```

The S4 casing also helps reduce uncontrolled ambient-light variation, although it does not eliminate the need for calibration.

A remaining risk is that excessive confirmation can reject a valid marking when the robot crosses it quickly.

This is why floor-event testing must be performed:

```text
while moving
```

and not only with the robot stationary.

---

# 5.11 Parking Risks

<div align="center">

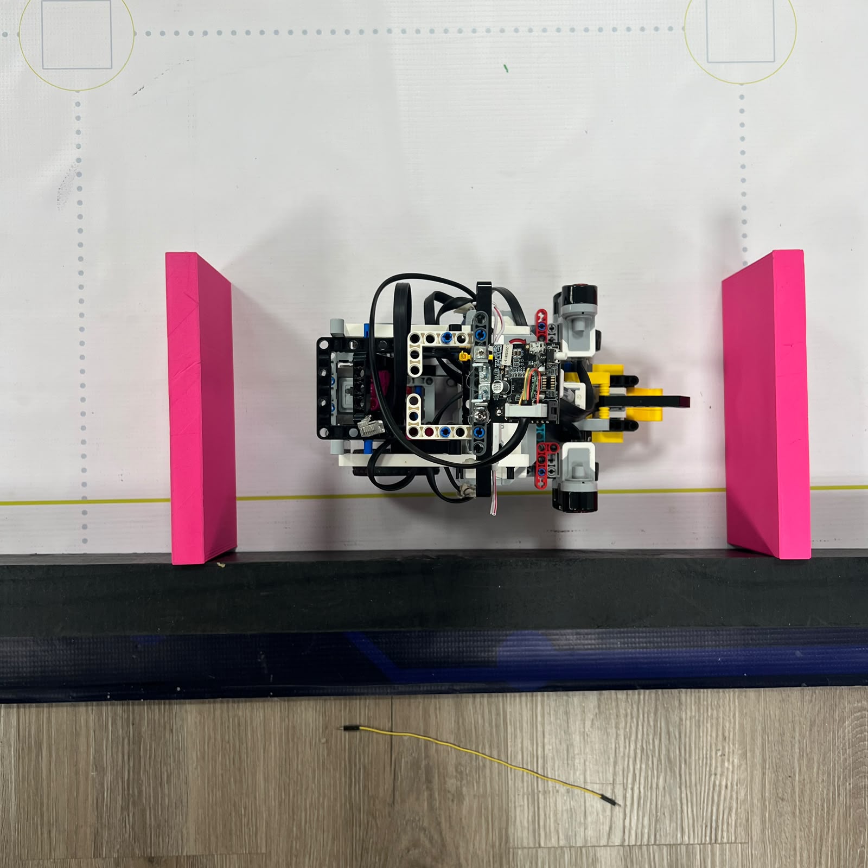
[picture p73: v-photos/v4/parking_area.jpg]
Parking area used for Piolín final maneuver testing


<br>

<sub><b>Figure 5.6.</b> Parking is a terminal maneuver, so errors in progression, perception, geometry, or stopping logic can all affect the final result.</sub>

</div>

Parking inherits risks from several earlier subsystems.

Possible failures include:

```text
course count incorrect

Pink detected too early

Pink target not confirmed

entry begins from poor pose

entry arc too wide or too tight

alignment incomplete

final travel overshoots

STOP does not remain terminal
```

The mitigation is to divide parking into phases:

```text
ELIGIBILITY
      ↓
PINK CONFIRMATION
      ↓
APPROACH
      ↓
ENTRY
      ↓
ALIGNMENT
      ↓
FINAL POSITION
      ↓
STOP
```

Each phase can be tested independently.

The final movement also uses:

```text
Motor A encoder progression
```

rather than time alone.

However, encoder progression is not treated as perfect absolute localization.

Final parking can additionally use:

```text
S2/S3 geometry

Motor B position

parking state
```

before accepting the final condition.

The current prototype value:

```text
PARK_EXTRA_DEG = 300
```

remains a development value and is not considered a final risk mitigation until repeated physical testing validates the endpoint.

---

# 5.12 Power, Connection, and Configuration Risks

Piolín's current electrical system is intentionally simple.

The active power source is:

```text
LEGO Mindstorms EV3 Rechargeable DC Battery 45501
```

and the current robot does not require a permanent:

```text
external battery

Arduino power system

buck converter
```

This reduces the number of active electrical failure points.

However, configuration risk still exists because S1 changes by round.

The critical mapping is:

```text
OPEN
S1 = Gyro
```

```text
OBSTACLES
S1 = Pixy2.1
```

A dangerous mismatch would be:

```text
Obstacle hardware installed
+
Open software started
```

or the opposite.

Mitigation includes:

```text
separate source programs

clear wiring documentation

round-specific startup procedure

physical S1 photographs

descriptive filenames
```

The repository should never imply that Gyro and Pixy2.1 are simultaneously active.

Connection inspection should also occur before competition-style runs because a software algorithm cannot compensate for a physically disconnected sensor.

---

# 5.13 Software Regression and Reproducibility Risks

One of the less visible but important risks is losing a working behavior while trying to improve another one.

For example:

```text
change corner steering
→ accidentally changes post-corner pose
→ obstacle behavior becomes worse
→ parking entry also changes
```

A poor development workflow would continue editing the same code until the cause becomes unclear.

The mitigation is:

```text
KNOWN-GOOD BASELINE
      ↓
one primary change
      ↓
controlled test
      ↓
compare result
```

If the change improves behavior repeatedly:

```text
save / commit
```

If it makes behavior worse:

```text
restore known-good version
```

Regression testing should include major downstream functions when upstream behavior changes.

For example, after modifying:

```text
corner exit
```

the team should eventually check:

```text
next pillar acquisition

recovery

parking entry pose
```

because systems engineering considers propagation, not only the subsystem directly edited.

---

## 5.14 Risk Mitigation Through Telemetry

Many risks become harder to diagnose when only the final collision is observed.

Piolín's software therefore benefits from telemetry that exposes the internal decision chain.

Useful variables include:

```text
STATE

COURSE COUNT

S2 LEFT

S3 RIGHT

PIXY SIGNATURE

PIXY TARGET X

TARGET LOCK

REQUIRED PASS SIDE

WALL COMMAND

OBSTACLE COMMAND

SAFETY ACTIVE

FINAL COMMAND

MOTOR B TARGET

MOTOR B REAL
```

This allows failures to be localized.

For example:

```text
SIG: 2
PASS: RIGHT
OBS_CMD: RIGHT
FINAL: LEFT
```

indicates an arbitration problem.

While:

```text
SIG: 2
PASS: LEFT
```

indicates an interpretation problem.

And:

```text
FINAL: RIGHT
MOTOR B REAL: LEFT
```

moves investigation toward actuation.

The mitigation principle is:

> **The earlier the software can expose where the expected decision changed, the less likely the team is to modify the wrong subsystem.**

---

## 5.15 Fail-Safe Behavior and Defensive Programming

Not every uncertain condition should produce an aggressive reaction.

Several defensive patterns are used or planned across Piolín:

```text
clamp extreme controller values

filter short ultrasonic spikes

confirm visual targets

lock active targets

require release conditions

reduce speed during difficult maneuvers

use critical wall safety

retain current maneuver briefly after temporary camera loss

require course progress before parking

make STOP terminal
```

The general philosophy is:

```text
UNCERTAIN DATA
→ reduce confidence
```

rather than:

```text
UNCERTAIN DATA
→ maximum steering
```

For example:

```text
one Red-looking frame
```

should become:

```text
candidate
```

before:

```text
confirmed Red obstacle
```

Similarly:

```text
one missing Pixy frame
```

should not instantly reverse the active steering trajectory.

This creates more predictable behavior under temporary uncertainty.

---

## 5.16 Verification of Mitigations

A mitigation should be tested against the failure it is intended to prevent.

Examples include:

| Risk | Mitigation Test |
| :--- | :--- |
| S2/S3 reversed | Place object separately near each sensor |
| Duplicate floor count | Cross one line slowly and at normal speed |
| Far pillar selected | Present near and far targets together |
| Target switching | Make two signatures visible during active pass |
| Temporary target loss | Allow pillar to leave FOV during steering |
| Wall controller fighting AVOID | Compare obstacle command with final command |
| Recovery too early | Inspect pillar location when `RECOVER` begins |
| Recovery too late | Inspect wall approach after pillar clearance |
| Pink activates early | Expose Pink before required course progression |
| STOP resumes motion | Keep program running after final stop |
| Software regression | Repeat known-good representative test after change |

This prevents a mitigation from existing only on paper.

The engineering sequence should be:

```text
identify risk
      ↓
implement defense
      ↓
deliberately test relevant scenario
      ↓
observe whether failure propagation is reduced
```

---

## 5.17 System-Level Failure Containment

The strongest risk strategy is to prevent one subsystem failure from controlling the entire robot.

Piolín's architecture can be visualized as:

```text
                         SENSOR INPUT
                              │
                              ▼
                          VALIDATION
                              │
                    bad data rejected?
                         /         \
                       YES          NO
                       │             │
                       ▼             ▼
                    IGNORE       PERCEPTION
                                      │
                                      ▼
                                 CONFIRMATION
                                      │
                                      ▼
                                  STATE LOGIC
                                      │
                                      ▼
                                CONTROLLER
                                      │
                                      ▼
                               ARBITRATION
                                      │
                                      ▼
                                SAFETY CHECK
                                      │
                                      ▼
                                FINAL COMMAND
                                      │
                                      ▼
                                  MOTOR B
```

Several containment boundaries exist:

```text
sensor validation
→ contains measurement errors

target confirmation
→ contains unstable perception

state machine
→ contains inappropriate controller activation

arbitration
→ contains controller conflict

wall safety
→ contains dangerous trajectory requests

command limits
→ contain excessive actuator requests
```

No layer guarantees perfect behavior, but multiple independent defenses reduce the probability that one incorrect observation immediately becomes a severe physical failure.

---

## 5.18 Highest-Priority Remaining Risks

Several risks still require significant physical validation before the Obstacle Challenge controller can be considered mature.

### 1. Relevant pillar selection

The final multi-block relevance function is not yet fully calibrated.

### 2. Obstacle authority vs. wall control

The exact amount of wall influence that should remain during `AVOID` still requires testing.

### 3. Pillar pass confirmation

The final combination of Pixy and ultrasonic evidence for releasing the target remains under development.

### 4. Recovery timing

Recovery must begin neither too early nor too late.

### 5. Pillars near corners

The transition between `CORNER` and obstacle handling is still one of the more complex interaction cases.

### 6. Final RGB thresholds

Floor detection must be validated dynamically under the final optical installation.

### 7. Parking geometry

Final entry, alignment, encoder progression, and stopping tolerances require measured repeatability.

Documenting these as active risks is preferable to presenting unfinished behavior as solved.

---

## 5.19 Final Engineering Assessment

Piolín's risk-management strategy is based on preventing uncertain information or a local subsystem error from immediately becoming a severe vehicle-level failure.

The current architecture uses several layers of mitigation:

```text
physical inspection

fixed sensor conventions

measurement validation

short filtering

candidate confirmation

target locking

state-based behavior

controller arbitration

critical wall safety

bounded steering

state-dependent speed

course-progress gating

encoder-supported parking

terminal STOP logic

telemetry

known-good software baselines
```

Several important examples demonstrate the systems approach.

```text
Pixy may temporarily lose a pillar
→ preserve target state instead of reversing immediately
```

```text
normal wall control may oppose pillar avoidance
→ reduce its authority during AVOID
```

```text
one floor marking produces many samples
→ latch it as one physical event
```

```text
Pink may be visible early
→ require course completion before parking can activate
```

```text
encoder travel is not perfect localization
→ combine it with physical parking geometry
```

```text
a correct command may still produce the wrong physical steering
→ compare requested and actual Motor B state
```

Not every risk has been eliminated, and several high-priority behaviors remain under active testing.

The objective is instead to ensure that each major risk has:

```text
a known cause or failure mechanism

a defined detection method

a mitigation strategy

a test that can verify the mitigation
```

The central risk-management principle used by PiolínTech is:

> **A robust autonomous system should not assume that every sensor reading, state transition, or actuator response is correct. Piolín's software is structured so that important decisions are validated, dangerous commands can be limited or overridden, failures can be traced to the layer where they begin, and improvements can be verified through repeatable physical tests.**

This approach turns risk management from a list of possible failures into an active part of Piolín's mechanical design, control architecture, software organization, testing process, and competition strategy.

---

<div align="center">

### [← Back to PiolínTech Main README](../../README.md)

</div>

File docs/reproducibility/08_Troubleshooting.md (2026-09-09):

# 8. Troubleshooting

<div align="center">

Piolín autonomous vehicle used for troubleshooting and validation

<br>

<sub><b>Figure 8.1.</b> Troubleshooting Piolín requires diagnosing the complete mechatronic system rather than assuming every failure originates in software.</sub>

</div>

Troubleshooting Piolín follows a simple engineering rule:

> **Find the first layer that behaves incorrectly before changing the next one.**

Autonomous failures often appear at the end of a long chain.

For example:

```text
sensor mounted incorrectly
        ↓
distance measurement becomes wrong
        ↓
controller calculates wrong steering
        ↓
Piolín exits corner badly
        ↓
next straight begins incorrectly
        ↓
later collision occurs
```

The collision is the visible symptom, but it is not necessarily the original failure.

For this reason, PiolínTech diagnoses problems in the following order:

```text
MECHANICS
    ↓
WIRING
    ↓
RAW SENSOR DATA
    ↓
SOFTWARE INTERPRETATION
    ↓
NAVIGATION STATE
    ↓
MOTOR COMMAND
    ↓
PHYSICAL RESPONSE
```

The objective is to avoid compensating for a physical or sensing problem by adding increasingly complex software corrections.

---

## 8.1 First Diagnostic Rule

Before changing any control constant, answer these questions:

```text
Is the robot mechanically intact?

Is the correct round configuration installed?

Are the ports correct?

Do raw sensor values make sense?

Does the software interpret those values correctly?

Is the correct navigation state active?

Is the intended motor command being produced?

Does the physical robot respond to that command correctly?
```

If one answer is already wrong, stop there.

There is little value in tuning a controller if its input assumptions are incorrect.

The current fixed hardware conventions are:

```text
Motor A = propulsion

Motor B = steering

S2 = LEFT Ultrasonic

S3 = RIGHT Ultrasonic

S4 = Color Sensor
```

Only S1 changes:

```text
OPEN
S1 = Gyro
```

```text
OBSTACLES
S1 = Pixy2.1
```

The Gyro and Pixy2.1 are never part of the same active configuration.

---

# 8.2 Quick Troubleshooting Table

Use this table to decide where to begin.

| Symptom | First Area to Check |
| :--- | :--- |
| Robot does not move | Motor A / Port A / drivetrain |
| Robot drives backward unexpectedly | Motor A polarity / software command |
| Steering does not move | Motor B / Port B |
| Steering moves opposite direction | Steering sign / linkage orientation |
| Robot never drives straight | Steering center / gyro / wall control |
| Robot zig-zags | Controller strength, steering center, delay |
| Robot constantly goes toward one wall | S2/S3 mapping, correction sign |
| Open starts directly into wall | Initial acquisition / steering / sensor geometry |
| Blue selects wrong direction | Color-state mapping |
| Orange selects wrong direction | Color-state mapping |
| Direction changes during run | Direction state overwritten |
| One line counted twice | Color event lock / re-arm |
| Corner starts too late | Detection, speed, state logic |
| Corner rotates wrong direction | Gyro sign / steering sign |
| Corner completes but next straight is bad | Corner exit / geometry reacquisition |
| Pixy sees nothing | S1, communication, signatures, lighting |
| Red causes left pass | Signature mapping / obstacle rule |
| Green causes right pass | Signature mapping / obstacle rule |
| Pixy detects pillar but robot ignores it | Target relevance / state transition |
| Robot reacts to distant pillar | Relevance threshold too permissive |
| Robot switches pillars mid-pass | Target lock |
| Pillar disappears and steering reverses | Target-loss handling |
| Robot passes pillar but hits wall | Recovery / control arbitration |
| Pillar avoidance feels inverted after a corner | State or controller interaction |
| Parking triggers too early | Progress-state logic |
| Parking position varies | Approach geometry / encoder / steering center |
| Same code behaves differently after rebuild | Mechanical or sensor recalibration |

This table identifies the **first diagnostic area**, not necessarily the final cause.

---

# 8.3 Mechanical Problems First

<div align="center">

Bottom view of Piolín showing drivetrain, steering and sensor integration

<br>

<sub><b>Figure 8.2.</b> Mechanical problems can change sensor readings and motor response even when the software is unchanged.</sub>

</div>

Before debugging software, inspect the physical vehicle.

### Steering

Check:

```text
Motor B securely mounted?

steering linkage connected?

front wheels approximately centered?

left and right movement free?

no part touching chassis?

no axle partially disconnected?
```

A mechanical steering problem often appears in software as:

```text
weak correction

different left/right response

corner inconsistency

failure to return to center
```

If Motor B is commanded correctly but the physical wheels do not move as expected, do not compensate with larger control gains.

Fix the mechanism first.

<div align="center">

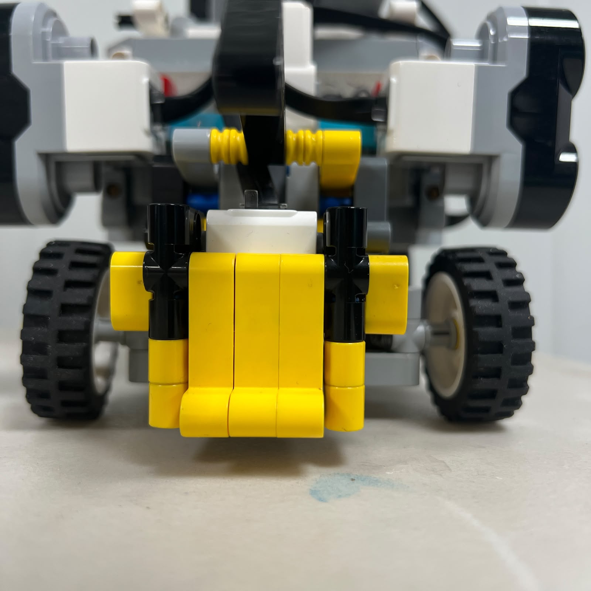
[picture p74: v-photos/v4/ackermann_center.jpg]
Piolín steering mechanism at center


<br>

<sub><b>Figure 8.3.</b> Steering center should be mechanically repeatable before navigation tuning begins.</sub>

</div>

### Drivetrain

Inspect:

```text
rear wheels secure?

axles aligned?

Motor A mount secure?

no wheel rubbing?

drivetrain moving freely?
```

<div align="center">

Piolín rear drivetrain inspection

<br>

<sub><b>Figure 8.4.</b> Unexpected drivetrain resistance can change physical travel distance and invalidate previously working timing or encoder values.</sub>

</div>

If the drivetrain changed physically, previously calibrated:

```text
speed

encoder distance

reverse displacement

parking movement
```

may require verification.

---

# 8.4 Wiring and Port Errors

The next layer is electrical configuration.

The permanent mapping is:

```text
A  → Large Motor

B  → Medium Motor

S2 → LEFT Ultrasonic

S3 → RIGHT Ultrasonic

S4 → Color Sensor
```

The most common high-impact wiring mistake would be swapping S2 and S3.

<div align="center">

Piolín ultrasonic mapping showing S2 left and S3 right

<br>

<sub><b>Figure 8.5.</b> Permanent ultrasonic identity: S2 is LEFT and S3 is RIGHT.</sub>

</div>

If the software assumes:

```text
S2 = LEFT
```

but the physical robot has:

```text
S2 = RIGHT
```

then a correct wall correction can become physically inverted.

Always verify wiring before reversing steering polarity in software.

### Open wiring

<div align="center">

Piolín Open Challenge wiring

<br>

<sub><b>Figure 8.6.</b> Open configuration requires the Gyro Sensor on S1.</sub>

</div>

```text
S1 = Gyro
```

### Obstacle wiring

<div align="center">

Piolín Obstacle Challenge wiring

<br>

<sub><b>Figure 8.7.</b> Obstacle configuration requires Pixy2.1 on S1.</sub>

</div>

```text
S1 = Pixy2.1
```

Running the wrong program with the wrong S1 device is a configuration failure, not a navigation failure.

---

# 8.5 Raw Sensor Diagnosis

Once hardware and wiring are correct, inspect raw sensor data before looking at steering behavior.

The diagnostic principle is:

```text
RAW SENSOR WRONG
→ fix sensing first
```

```text
RAW SENSOR RIGHT
+
BEHAVIOR WRONG
→ investigate interpretation / control
```

### Ultrasonics

Move Piolín physically closer to the left wall.

Expected:

```text
S2 changes accordingly
```

Move Piolín closer to the right wall.

Expected:

```text
S3 changes accordingly
```

If the wrong variable changes, the physical or software mapping is incorrect.

If the correct variable changes but steering reacts the wrong way, the problem is later in the control chain.

### Color Sensor

Test:

```text
normal floor

Blue

Orange
```

with the current casing installed.

<div align="center">

Piolín Color Sensor casing

<br>

<sub><b>Figure 8.8.</b> Color troubleshooting must use the same casing and physical installation used during calibration.</sub>

</div>

### Gyro

Rotate Piolín manually and observe:

```text
angle magnitude

angle sign

return toward original heading
```

### Pixy2.1

Place one known target ahead and inspect:

```text
signature

x

y

width

height
```

Do not begin by debugging obstacle steering if the camera itself reports the wrong target.

---

# 8.6 Open Challenge Troubleshooting

Open combines three main information sources:

```text
Gyro
→ heading

S2/S3
→ lateral geometry

S4
→ course progression
```

When a failure occurs, determine which information became incorrect first.

### Robot leaves start and immediately crashes

Check in this order:

```text
1. Steering center.

2. Motor B direction.

3. S2/S3 mapping.

4. Initial wall geometry.

5. Gyro zero.

6. Initial acquisition logic.
```

Do not immediately increase steering strength.

If Piolín begins from an outside position and drives directly toward the inner wall, the key question is:

```text
Did software understand where the robot started?
```

before asking:

```text
Was steering strong enough?
```

### Robot starts in a circle

Possible causes:

```text
Motor B not centered

steering center calibration wrong

gyro heading correction sign wrong

wall-control sign wrong

sensor mapping reversed
```

A constant circle usually suggests a persistent steering bias rather than random sensor noise.

---

## 8.7 Open Direction Problems

Current direction selection is:

```text
BLUE first
→ COUNTERCLOCKWISE
```

```text
ORANGE first
→ CLOCKWISE
```

If Blue produces clockwise behavior, inspect the direction mapping directly.

Do not swap S2 and S3 to compensate.

After direction is established:

```text
CCW
S2 = inner
S3 = outer
```

```text
CW
S3 = inner
S2 = outer
```

The physical ports never change.

If the first corner works but later corners suddenly appear mirrored, inspect whether the software has accidentally changed:

```text
direction

inner_sensor

outer_sensor

steering polarity
```

during a state transition.

Direction should normally be established once and remain persistent for the run.

---

# 8.8 Open Straight-Line Problems

A stable straight depends on both heading and lateral geometry.

If Piolín zig-zags:

```text
check steering center first
      ↓
check raw S2/S3 stability
      ↓
check gyro behavior
      ↓
then examine correction strength
```

Possible control causes include:

```text
correction too strong

correction applied too frequently

insufficient deadband

delayed response

gyro and wall correction fighting each other
```

The desired relationship is:

```text
Ultrasonic
→ lateral correction
```

```text
Gyro
→ heading correction
```

If the robot has correct heading but is consistently too close to one wall, changing gyro gains is unlikely to solve the underlying lateral error.

If lateral distance looks correct but the chassis is visibly rotated, wall control alone is not enough.

---

# 8.9 Open Corner Problems

Corner failures should be divided into:

```text
ENTRY

TURN

EXIT
```

### Entry failure

Symptoms:

```text
starts too late

starts too early

starts from wrong lateral position
```

Investigate:

```text
color event

geometry transition

vehicle speed

current course state
```

### Turn failure

Symptoms:

```text
rotates too much

rotates too little

turns wrong direction
```

Investigate:

```text
steering sign

gyro sign

steering strength

turn-release logic
```

### Exit failure

Symptoms:

```text
correct rotation but hits wall after turn

zig-zags after turn

does not return to normal straight control
```

Investigate:

```text
gyro release

steering return

S2/S3 reacquisition

state transition back to straight
```

A corner should not be debugged as one indivisible event.

The first incorrect stage is the important one.

---

# 8.10 Double-Counting Course Events

If Piolín physically crosses one marking but the software counts two:

```text
physical event = 1

software events > 1
```

the likely problem is not color classification itself.

Inspect:

```text
event lock

re-arm condition

cooldown

state transition
```

The desired logic is:

```text
neutral
  ↓
color detected
  ↓
count ONCE
  ↓
lock
  ↓
leave marking
  ↓
re-arm
```

If neutral floor is unreliable, the release condition may need to use another robust state transition rather than simply removing protection against duplicates.

---

# 8.11 Gyro Troubleshooting

<div align="center">

Piolín Gyro Sensor orientation

<br>

<sub><b>Figure 8.9.</b> Gyro troubleshooting begins with physical orientation and sign verification before control gains are modified.</sub>

</div>

### Gyro starts with unexpected angle

Check:

```text
robot stationary during reset?

reset actually executed?

sensor orientation unchanged?
```

### Gyro sign seems reversed

Rotate Piolín manually.

If clockwise physical rotation produces the opposite sign from what the code expects, correct the interpretation centrally.

Do not compensate by reversing unrelated corner logic in multiple places.

### Gyro appears correct but robot oscillates

The problem may be:

```text
gain strength

derivative response

steering delay

mechanical center

wall correction interaction
```

A correct sensor can still be used incorrectly by the controller.

---

# 8.12 Pixy2.1 Troubleshooting

<div align="center">

Piolín Pixy2.1 vision sensor

<br>

<sub><b>Figure 8.10.</b> Pixy troubleshooting should distinguish communication, detection, target selection, and steering problems.</sub>

</div>

The current camera configuration uses:

```text
S1 = Pixy2.1
```

with:

```text
sig1 = Pink

sig2 = Red

sig3 = Green
```

The current Pixy2.1 also includes a **3D-printed casing**.

The casing is part of the calibrated installation, so camera behavior should be rechecked if:

```text
casing moves

camera moves inside casing

camera angle changes

front assembly changes
```

### Pixy sees nothing

Check:

```text
S1 connection

correct Obstacle software

I2C/SMBus communication

camera power/connection

signature training

lighting

target inside field of view
```

<div align="center">

Pixy2.1 S1 connection

<br>

<sub><b>Figure 8.11.</b> Verify the current direct S1 connection before changing vision parameters.</sub>

</div>

### Pixy detects wrong color

Check signature training first.

Expected:

```text
Red → sig2

Green → sig3

Pink → sig1
```

The software and camera training must agree.

---

# 8.13 Red/Green Passing Direction Is Wrong

This is one of the most important obstacle diagnostic rules.

The competition logic is fixed:

```text
RED
→ PASS RIGHT
```

```text
GREEN
→ PASS LEFT
```

This rule is based on the pillar color, not on where the pillar appears inside the image.

Therefore:

```text
Red appears left of image center
```

still means:

```text
PASS RIGHT
```

and:

```text
Green appears right of image center
```

still means:

```text
PASS LEFT
```

If Piolín does the opposite, inspect:

```text
1. Was the signature correct?

2. Was the target selected correctly?

3. Did the software map the signature to the correct side?

4. Did the intended steering command have the correct sign?

5. Did another controller override the command?
```

Do not reverse the complete steering system before identifying which stage is actually inverted.

---

# 8.14 When Pixy Detects Correctly but the Robot Goes the Wrong Way

This symptom is especially useful because it narrows the diagnosis.

Suppose debug output says:

```text
RED detected
PASS RIGHT requested
```

but Piolín physically goes left.

Then camera classification is probably not the first failure.

Investigate:

```text
steering-command sign

Motor B polarity

steering conversion

wall-control override

corner-control override

recovery state accidentally active
```

The chain is:

```text
RED
  ↓
RIGHT objective
  ↓
steering command
  ↓
Motor B
  ↓
physical wheel angle
```

Find the first stage where "right" becomes "left."

---

# 8.15 Controller Conflict During Obstacle Avoidance

A common obstacle failure is when Pixy requests one trajectory while normal wall control requests another.

For example:

```text
Pixy:
move right of Red
```

while:

```text
wall controller:
return toward center
```

If both are applied with similar authority:

```text
commands fight
      ↓
weak obstacle response
      ↓
zig-zag
      ↓
wrong passing side
```

The intended priority is state-dependent.

```text
NORMAL
→ geometry control dominant
```

```text
ACTIVE PILLAR
→ pillar objective dominant
→ wall safety still active
```

```text
PILLAR CLEARED
→ recovery regains authority
```

If pillar avoidance feels randomly weak or appears inverted even though the color rule is correct, inspect controller arbitration before reversing the Pixy rule.

---

# 8.16 Distant Pillars Affect Steering

If Piolín begins steering strongly toward a pillar that is still far away, target relevance may be too permissive.

Check:

```text
block size

image position

current state

target-selection condition
```

The desired relationship is:

```text
visible
≠
automatically dominant
```

A target should become strongly influential only when it is relevant to the current vehicle trajectory.

Very small or distant visual blocks may be useful for awareness without requiring immediate maximum steering.

---

# 8.17 Multiple Pillars and Wrong Target Selection

If Red and Green are visible simultaneously, the first block returned by Pixy should not automatically be considered the correct obstacle.

Investigate target-selection logic.

Useful evidence can include:

```text
signature

x

y

width

height

current maneuver state

previous target
```

Typical failure:

```text
near Red ahead

far Green visible

software chooses Green
      ↓
wrong avoidance trajectory
```

The problem is then:

```text
TARGET SELECTION
```

not:

```text
COLOR RULE
```

These are separate layers and should remain separate in troubleshooting.

---

# 8.18 Target Lock Problems

### Robot changes from one pillar to another mid-pass

Target lock may be too weak.

Expected:

```text
select pillar
      ↓
temporarily commit
      ↓
complete pass
      ↓
release
```

### Robot ignores the next pillar

Target lock may be too strong or release logic may be incomplete.

A lock should be:

```text
temporary
```

not:

```text
permanent until program ends
```

Check debug state after the first obstacle.

The important question is:

```text
Did software return from PILLAR_ACTIVE to a state that can acquire another target?
```

---

# 8.19 Target Loss Problems

A target disappearing from Pixy's field of view does not automatically mean it has been passed.

Piolín's own steering changes camera orientation.

Therefore:

```text
pillar leaves frame
```

can mean:

```text
camera turned away
```

rather than:

```text
vehicle cleared pillar
```

If the robot immediately reverses steering when detection disappears, inspect target-loss handling.

A more robust sequence is:

```text
recent target retained briefly
      ↓
current maneuver continues
      ↓
S2/S3 geometry evaluated
      ↓
pillar clearance confirmed
      ↓
target released
```

Target loss and target clearance should be treated as different states.

---

# 8.20 Pillar Is Passed but Robot Still Crashes

<div align="center">

Piolín red obstacle maneuver

<br>

<sub><b>Figure 8.12.</b> Avoiding the pillar is only one part of the maneuver; recovery must also restore a useful track trajectory.</sub>

</div>

If Piolín passes the obstacle correctly but then hits a wall, the avoidance itself may already be successful.

Investigate:

```text
target release

countersteering

recovery timing

S2/S3 wall geometry

normal-control reactivation
```

The full maneuver is:

```text
DETECT
  ↓
AVOID
  ↓
PASS
  ↓
RELEASE
  ↓
COUNTERSTEER
  ↓
RECOVER
```

Do not weaken the initial avoidance merely because the recovery afterward is incorrect.

That can turn:

```text
successful pass + bad recovery
```

into:

```text
pillar collision
```

without solving the actual problem.

---

# 8.21 Why Obstacle Steering Can Appear Inverted After a Corner

If Red and Green behave correctly before a corner but appear inverted after it, do not assume Pixy has suddenly reversed its coordinate system.

Check:

```text
current navigation state

left/right steering sign

last active maneuver

target lock

corner controller still active?

wall controller influence

software direction variables
```

The physical rule remains:

```text
Red → RIGHT

Green → LEFT
```

throughout the course.

A failure that appears only after a state transition often indicates a **state-management or controller-interaction problem**, not a camera-color problem.

---

# 8.22 Color Sensor Troubleshooting

<div align="center">

Bottom view of Piolín Color Sensor

<br>

<sub><b>Figure 8.13.</b> Floor detection should be diagnosed at the sensor, classification, and event-state levels separately.</sub>

</div>

### Color not detected

Check:

```text
S4 connection

sensor position

sensor height

casing

raw reading

classification range
```

### Correct color detected but wrong direction

Then the problem is not optical classification.

Check:

```text
Blue/Orange state mapping
```

### Color detected several times

Check:

```text
event lock

re-arm condition

cooldown
```

### Works stationary but fails while moving

Check:

```text
vehicle speed

confirmation count

sampling delay

sensor crossing time
```

Avoid widening thresholds immediately unless raw dynamic data shows classification itself is failing.

---

# 8.23 Parking Troubleshooting

<div align="center">

Piolín parking area

<br>

<sub><b>Figure 8.14.</b> Parking errors should be separated into state, approach, steering, and final-displacement problems.</sub>

</div>

Parking depends on the entire run state.

Possible failure categories include:

### Parking begins too early

Check:

```text
course counter

lap state

parking-enable condition

duplicate Color Sensor event
```

### Parking begins too late

Check:

```text
missed course event

parking trigger

final approach condition
```

### Parking starts correctly but stops in wrong place

Check:

```text
Motor A displacement

approach heading

steering center

wall geometry

physical drivetrain repeatability
```

### Pixy Pink appears but parking should not start

During Obstacles:

```text
sig1 = Pink
```

is a visual parking reference.

It should not automatically override course progression.

The desired logic is closer to:

```text
correct progress
+
parking state active
+
Pink reference valid
+
physical approach valid
```

before the final sequence begins.

---

# 8.24 Software Runtime Problems

Not every failure occurs after the robot begins moving.

### Open program does not start

Check:

```text
Pybricks runtime

file location

syntax/import errors

correct hardware objects
```

### Obstacle program does not start

Check:

```text
Python 3

ev3dev2 availability

SMBus/I2C availability

Pixy interface
```

### IDE reports missing EV3 libraries

Desktop editors may report that packages such as:

```text
ev3dev2
```

cannot be resolved locally.

This does not automatically mean the package is unavailable on the EV3.

Separate:

```text
editor language-server warning
```

from:

```text
actual EV3 runtime failure
```

The authoritative test is whether the program imports and runs in the intended EV3 environment.

---

# 8.25 Debug Output

Debug output should help identify the first incorrect state.

### Useful Open values

```text
direction

navigation state

corner count

S2

S3

gyro angle

steering command
```

A compact conceptual line is:

```text
DIR: CCW | STATE: STRAIGHT | TURN: 3 | S2: ... | S3: ... | G: ... | STEER: ...
```

### Useful Obstacle values

```text
state

selected signature

x

y

width

height

S2

S3

steering command
```

For example:

```text
STATE: AVOID | SIG: 2 | X: ... | W: ... | S2: ... | S3: ... | STEER: RIGHT
```

When the robot does something unexpected, compare:

```text
what the robot physically did
```

with:

```text
what the software believed it was doing
```

This distinction can immediately reveal whether the failure is perception, interpretation, or actuation.

---

# 8.26 Use Video as Diagnostic Evidence

Video is especially useful when a maneuver occurs too quickly to understand during the run.

A useful recording should show as much as practical of:

```text
starting position

track geometry

front steering

pillar position

corner entry

wall clearance

recovery
```

When possible, synchronize the video with software debug output or record the corresponding test ID.

Useful questions while reviewing a run include:

```text
Where was Piolín when steering first changed?

Was that change physically appropriate?

When did the camera lose the pillar?

When did recovery begin?

Did the front wheels actually follow the command?

Did the failure begin before the visible collision?
```

The purpose of video is not only presentation.

It is measurement evidence for timing and state transitions.

---

# 8.27 Return to a Known-Good Version

When an experimental modification creates several new problems, do not continue stacking fixes indefinitely.

Use Git to return to the most recent known-good version.

The process is:

```text
KNOWN-GOOD
    ↓
one experimental change
    ↓
test
```

If significantly worse:

```text
reject change
    ↓
return to baseline
```

If better:

```text
record result
    ↓
commit improvement
```

This prevents Piolín from accumulating many interacting changes until the original working behavior can no longer be recovered.

---

# 8.28 Recalibration After Physical Changes

The same software should not be assumed to behave identically after mechanical work.

Recheck the relevant subsystem after:

```text
steering rebuild

Motor B remounting

Motor A remounting

wheel change

drivetrain repair

ultrasonic movement

Color Sensor movement

Color Sensor casing change

Gyro movement

Pixy movement

Pixy 3D-casing change

camera orientation change
```

For example:

```text
Pixy behavior changed after casing work
```

should first trigger:

```text
camera position / orientation verification
```

rather than:

```text
rewrite target-selection algorithm
```

Likewise:

```text
Open suddenly drifts after steering repair
```

should first trigger:

```text
steering center verification
```

rather than immediately retuning gyro gains.

---

# 8.29 Recommended Diagnostic Workflow

When the cause is unclear, use this complete sequence.

```text
1. Stop Piolín.

2. Record the failed test.

3. Inspect mechanical condition.

4. Verify wiring.

5. Verify correct round configuration.

6. Test motors individually.

7. Read raw sensors.

8. Verify sensor mapping.

9. Verify software state.

10. Verify calculated steering command.

11. Compare command with physical wheel response.

12. Identify first incorrect layer.

13. Change one relevant variable.

14. Repeat the same test.

15. Compare against the previous result.
```

Do not skip directly from:

```text
"robot crashed"
```

to:

```text
"change PID"
```

without identifying whether PID was actually responsible.

---

# 8.30 Troubleshooting by Layer

The complete diagnostic structure can be summarized as:

```text
                    FAILURE OBSERVED
                           │
                           ▼
                     MECHANICAL?
                    /          \
                  YES          NO
                   │            │
                  FIX           ▼
                            ELECTRICAL?
                            /       \
                          YES       NO
                           │         │
                          FIX        ▼
                              RAW SENSOR?
                              /       \
                            WRONG     RIGHT
                              │         │
                             FIX        ▼
                                INTERPRETATION?
                                  /       \
                                WRONG     RIGHT
                                  │         │
                                 FIX        ▼
                                      STATE LOGIC?
                                       /      \
                                     WRONG    RIGHT
                                       │        │
                                      FIX       ▼
                                           CONTROL?
                                            /    \
                                          WRONG  RIGHT
                                            │      │
                                           FIX     ▼
                                              PHYSICAL
                                               RESPONSE
```

This structure makes troubleshooting repeatable.

---

# 8.31 Current Known Development Areas

Some Piolín behaviors are still under active development and should therefore receive extra attention during diagnosis.

### Open

```text
initial acquisition from different starting positions

corner consistency

corner exit geometry

multi-lap stability

final parking
```

### Obstacles

```text
Pixy target relevance

multiple-block selection

target lock

target-loss handling

Red/Green steering consistency

controller arbitration

pillar-pass confirmation

post-pillar recovery

parking
```

A failure in one of these areas does not mean the architecture itself is invalid.

It means the current implementation still requires testing and tuning.

The repository should distinguish clearly between:

```text
known architecture
```

and:

```text
unfinished performance tuning
```

---

# 8.32 Final Troubleshooting Checklist

Before modifying navigation code, verify:

| Check | Required |
| :--- | :--- |
| Mechanical structure intact | Yes |
| Steering center verified | Yes |
| Drivetrain free | Yes |
| Correct round hardware installed | Yes |
| Motor A on A | Yes |
| Motor B on B | Yes |
| S2 physically LEFT | Yes |
| S3 physically RIGHT | Yes |
| S4 working | Yes |
| Correct S1 device | Yes |
| Raw sensor values plausible | Yes |
| Software mapping matches hardware | Yes |
| Navigation state correct | Yes |
| Steering command known | Yes |
| Physical steering response matches command | Yes |

For Obstacles also verify:

| Pixy Check | Required |
| :--- | :--- |
| 3D-printed casing secure | Yes |
| S1 connection secure | Yes |
| `sig1 = Pink` | Yes |
| `sig2 = Red` | Yes |
| `sig3 = Green` | Yes |
| Red rule = RIGHT | Yes |
| Green rule = LEFT | Yes |
| Correct target selected | Yes |
| Target lock state known | Yes |

---

# 8.33 Final Engineering Assessment

Troubleshooting Piolín is most effective when the robot is treated as a chain of connected physical and software systems rather than as a program that occasionally makes mistakes.

The diagnostic sequence is:

```text
MECHANICS
→ WIRING
→ RAW SENSING
→ INTERPRETATION
→ STATE
→ CONTROL
→ ACTUATION
```

A failure should be corrected at the earliest layer where the expected behavior becomes incorrect.

This distinction is especially important in the two current competition configurations.

During Open:

```text
S2/S3
→ lateral geometry

Gyro
→ heading

Color Sensor
→ course progression
```

During Obstacles:

```text
Pixy2.1
→ obstacle identity and visual geometry

S2/S3
→ physical boundary context

Color Sensor
→ course progression
```

The current Pixy2.1 must be evaluated with its **3D-printed casing installed**, because the casing is part of the calibrated camera assembly. Likewise, the Color Sensor should remain in its current cased installation when floor-detection problems are diagnosed.

One of the most important obstacle troubleshooting rules is that the competition mapping never changes:

```text
RED
→ PASS RIGHT

GREEN
→ PASS LEFT
```

If the vehicle physically does the opposite, the team should determine whether the failure occurred in:

```text
signature identification

target selection

rule mapping

controller arbitration

steering sign

physical steering response
```

instead of immediately reversing the full system.

Similarly, an Open collision should not automatically lead to stronger steering. The original problem may have been an incorrect start state, direction mapping, gyro reference, or corner exit several seconds earlier.

The final troubleshooting principle is:

> **Do not fix the last visible symptom. Find the first incorrect assumption in the system and correct it there.**

Using this method allows PiolínTech to preserve known-good behavior, reduce unnecessary code changes, and turn failures into useful engineering evidence rather than repeated trial-and-error.

---

<div align="center">

### [← Back to PiolínTech Main README](../../README.md)

</div>

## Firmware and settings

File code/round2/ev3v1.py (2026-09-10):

#!/usr/bin/env pybricks-micropython

# ================================================================
# PIOLIN - WRO FUTURE ENGINEERS 2026
# ROUND 2 / OBSTACLE CHALLENGE - EV3 V1
#
# EARLY PIXY + ULTRASONIC OBSTACLE PROTOTYPE
#
# Hardware:
#   Motor A = rear propulsion
#   Motor B = Ackermann steering
#
#   S1 = Pixy2.1
#   S2 = LEFT EV3 Ultrasonic Sensor
#   S3 = RIGHT EV3 Ultrasonic Sensor
#   S4 = EV3 Color Sensor
#
# Pixy2.1 signatures:
#   Signature 1 = PINK  / parking reference
#   Signature 2 = RED   / pass RIGHT
#   Signature 3 = GREEN / pass LEFT
#
# Main idea:
#   - Drive using simple lateral ultrasonic correction.
#   - Detect Red / Green pillars with Pixy2.1.
#   - The SIGNATURE fixes the legal passing side.
#   - Camera X/Y/size only change the strength of the maneuver.
#   - Side ultrasonics remain active as wall protection.
#   - Briefly remember a pillar if Pixy loses it.
#
# This file represents an early Round 2 development baseline.
# It is NOT the final Phase 4 obstacle controller.
#
# Missing from this V1:
#   - complete pillar pass-confirmation state
#   - dedicated RECOVER state
#   - full corner state machine
#   - three-lap completion logic
#   - final parking sequence
#   - advanced controller arbitration
# ================================================================


from pybricks.hubs import EV3Brick
from pybricks.ev3devices import Motor, UltrasonicSensor, ColorSensor
from pybricks.parameters import Port, Button, Stop
from pybricks.tools import wait, StopWatch

from pixycamev3.pixy2 import Pixy2


# ================================================================
# EV3
# ================================================================

EV3 = EV3Brick()


# ================================================================
# HARDWARE
# ================================================================

MOTOR_DRIVE = Motor(Port.A)
MOTOR_STEER = Motor(Port.B)

# Obstacle configuration:
# Pixy2.1 replaces the Open-round gyro on S1.
PIXY = Pixy2(
    port=1,
    i2c_address=0x54
)

# Physical identities are fixed.
US_LEFT = UltrasonicSensor(Port.S2)
US_RIGHT = UltrasonicSensor(Port.S3)

COLOR_SENSOR = ColorSensor(Port.S4)


# ================================================================
# PIXY SIGNATURES
# ================================================================

SIG_PINK = 1
SIG_RED = 2
SIG_GREEN = 3

# Signature bit mask:
#
# sig1 -> bit 0
# sig2 -> bit 1
# sig3 -> bit 2
#
# 0b00000111 = signatures 1, 2 and 3
PIXY_SIGNATURE_MASK = 0x07

MAX_PIXY_BLOCKS = 8


# ================================================================
# STEERING POLARITY
# ================================================================

# Piolin steering convention:
#
# positive steering -> LEFT
# negative steering -> RIGHT

STEER_LEFT = 1
STEER_RIGHT = -1

CENTER = 0


# ================================================================
# SPEED
# ================================================================

# On this Piolin build:
# negative Motor A speed = forward

SPEED_NORMAL = -280
SPEED_PILLAR = -200
SPEED_WALL_DANGER = -170


# ================================================================
# STEERING LIMITS
# ================================================================

MAX_STEER_ANGLE = 34

MAX_NORMAL_STEER = 13
MAX_PILLAR_STEER = 30

STEERING_MOTOR_SPEED = 800

# Limit how much the requested angle can change per loop.
# This reduces abrupt left/right oscillation.
MAX_STEER_STEP = 3.0

current_steer = 0.0


# ================================================================
# ULTRASONIC FILTERING
# ================================================================

# Measurements are handled in millimeters.

MIN_VALID_US_MM = 30
MAX_VALID_US_MM = 2000

FILTER_ALPHA = 0.40

filtered_left = None
filtered_right = None


# ================================================================
# NORMAL LATERAL CONTROL
# ================================================================

# V1 uses the difference between left and right distances as a
# simple lateral correction.
#
# This is NOT the more advanced Phase 4 geometry controller.

WALL_KP = 0.035

WALL_DEADBAND_MM = 25

# Strong protection if Piolin becomes too close to either side.
WALL_DANGER_MM = 180

WALL_DANGER_STEER = 25


# ================================================================
# PIXY VALIDATION
# ================================================================

# Ignore extremely small detections.
MIN_BLOCK_WIDTH = 4
MIN_BLOCK_HEIGHT = 5
MIN_BLOCK_AREA = 25

# Pixy2 image geometry is approximately:
# width  = 316
# height = 208

MIN_VALID_X = 0
MAX_VALID_X = 315

MIN_VALID_Y = 15
MAX_VALID_Y = 207


# ================================================================
# PILLAR CONTROL
# ================================================================

# These X positions do NOT decide the passing side.
#
# They only describe the desired image geometry while executing
# the already selected maneuver.

RED_TARGET_X = 85
GREEN_TARGET_X = 230


# Minimum steering when a relevant pillar is detected.
PILLAR_BASE_STEER = 11

# Additional steering as the pillar becomes more relevant.
PILLAR_MAX_EXTRA = 17

# Influence of horizontal image error on steering magnitude.
PIXY_X_GAIN = 0.035


# ================================================================
# TARGET MEMORY
# ================================================================

# Pixy may briefly lose the pillar while Piolin rotates.
# Do not immediately cancel the maneuver.

TARGET_MEMORY_MS = 300

last_target_signature = None
last_target_angle = 0.0
last_target_time = -10000

locked_tracking_index = None


# ================================================================
# LOOP
# ================================================================

LOOP_DELAY_MS = 20

clock = StopWatch()


# ================================================================
# GENERAL UTILITIES
# ================================================================

def clamp(value, minimum, maximum):

    if value < minimum:
        return minimum

    if value > maximum:
        return maximum

    return value


# ================================================================
# DISTANCE READING
# ================================================================

def read_ultrasonic(sensor):
    """
    Read one ultrasonic sensor.

    Pybricks returns distance in millimeters.

    Invalid or extreme readings return None instead of being used
    directly by the controller.
    """

    try:
        value = sensor.distance()

    except Exception:
        return None

    if value < MIN_VALID_US_MM:
        return None

    if value > MAX_VALID_US_MM:
        return None

    return float(value)


def update_ultrasonics():
    """
    Read and low-pass filter S2 and S3.

    Returns:
        left_mm, right_mm
    """

    global filtered_left
    global filtered_right

    raw_left = read_ultrasonic(US_LEFT)
    raw_right = read_ultrasonic(US_RIGHT)

    if raw_left is not None:

        if filtered_left is None:
            filtered_left = raw_left

        else:
            filtered_left = (
                FILTER_ALPHA * raw_left
                + (1.0 - FILTER_ALPHA) * filtered_left
            )

    if raw_right is not None:

        if filtered_right is None:
            filtered_right = raw_right

        else:
            filtered_right = (
                FILTER_ALPHA * raw_right
                + (1.0 - FILTER_ALPHA) * filtered_right
            )

    return filtered_left, filtered_right


# ================================================================
# STEERING MOTOR
# ================================================================

def set_steering(target, immediate=False):
    """
    Command Motor B while keeping the steering angle inside
    the mechanical software limit.

    Normal commands are rate-limited to reduce oscillation.
    """

    global current_steer

    target = clamp(
        target,
        -MAX_STEER_ANGLE,
        MAX_STEER_ANGLE
    )

    if immediate:

        current_steer = target

    else:

        difference = target - current_steer

        difference = clamp(
            difference,
            -MAX_STEER_STEP,
            MAX_STEER_STEP
        )

        current_steer += difference

    MOTOR_STEER.track_target(
        current_steer
    )


# ================================================================
# NORMAL WALL / LATERAL CONTROL
# ================================================================

def normal_steering(left, right):
    """
    Early lateral controller.

    If both sensors are valid, compare left and right clearance.

    If Piolin is closer to the left:
        steer RIGHT.

    If Piolin is closer to the right:
        steer LEFT.
    """

    if left is None or right is None:
        return 0.0

    error = left - right

    if abs(error) <= WALL_DEADBAND_MM:
        return 0.0

    correction = WALL_KP * error

    return clamp(
        correction,
        -MAX_NORMAL_STEER,
        MAX_NORMAL_STEER
    )


# ================================================================
# WALL SAFETY
# ================================================================

def wall_safety(left, right):
    """
    Strong local wall protection.

    Returns:
        steering angle if intervention is needed
        None otherwise
    """

    left_danger = (
        left is not None
        and left <= WALL_DANGER_MM
    )

    right_danger = (
        right is not None
        and right <= WALL_DANGER_MM
    )

    # If both are close, escape from the closer side.
    if left_danger and right_danger:

        if left < right:
            return -WALL_DANGER_STEER

        else:
            return WALL_DANGER_STEER

    # Too close to left wall -> steer right.
    if left_danger:
        return -WALL_DANGER_STEER

    # Too close to right wall -> steer left.
    if right_danger:
        return WALL_DANGER_STEER

    return None


# ================================================================
# PIXY BLOCK VALIDATION
# ================================================================

def valid_pillar(block):
    """
    Check whether a Pixy block is useful for obstacle navigation.
    """

    if block.sig not in (
        SIG_RED,
        SIG_GREEN
    ):
        return False

    if block.x_center < MIN_VALID_X:
        return False

    if block.x_center > MAX_VALID_X:
        return False

    if block.y_center < MIN_VALID_Y:
        return False

    if block.y_center > MAX_VALID_Y:
        return False

    if block.width < MIN_BLOCK_WIDTH:
        return False

    if block.height < MIN_BLOCK_HEIGHT:
        return False

    area = block.width * block.height

    if area < MIN_BLOCK_AREA:
        return False

    return True


# ================================================================
# TARGET SELECTION
# ================================================================

def choose_target(blocks):
    """
    Select one relevant Red or Green pillar.

    V1 already avoids blindly using the first Pixy block.

    If the previous tracking index is still visible, preserve it.
    Otherwise select the strongest candidate using image area and
    vertical position.

    Larger / lower blocks are generally treated as more relevant,
    but this is image-space relevance, not a metric distance.
    """

    global locked_tracking_index

    candidates = []

    for block in blocks:

        if valid_pillar(block):
            candidates.append(block)

    if not candidates:

        locked_tracking_index = None
        return None

    # ------------------------------------------------------------
    # KEEP THE SAME PIXY TRACK IF POSSIBLE
    # ------------------------------------------------------------

    if locked_tracking_index is not None:

        for block in candidates:

            block_index = getattr(
                block,
                "tracking_index",
                None
            )

            if block_index == locked_tracking_index:
                return block

    # ------------------------------------------------------------
    # SELECT MOST RELEVANT CANDIDATE
    # ------------------------------------------------------------

    def relevance(block):

        area = (
            block.width
            * block.height
        )

        # Y receives additional weight because a pillar lower in the
        # image is usually more relevant to the immediate maneuver.
        return area + block.y_center * 2

    target = max(
        candidates,
        key=relevance
    )

    locked_tracking_index = getattr(
        target,
        "tracking_index",
        None
    )

    return target


# ================================================================
# PIXY READING
# ================================================================

def read_pixy():
    """
    Request Pixy Color Connected Components blocks.

    Returns:
        selected Red/Green target
        None if no useful pillar is visible
    """

    try:

        count, blocks = PIXY.get_blocks(
            PIXY_SIGNATURE_MASK,
            MAX_PIXY_BLOCKS
        )

    except Exception as error:

        print(
            "PIXY ERROR:",
            error
        )

        return None

    if count <= 0:
        return None

    available = []

    for i in range(count):
        available.append(blocks[i])

    return choose_target(
        available
    )


# ================================================================
# PILLAR PROXIMITY / RELEVANCE
# ================================================================

def pillar_relevance(block):
    """
    Estimate how strongly Piolin should react.

    This does NOT attempt to convert Pixy coordinates into physical
    centimeters.

    It only creates a normalized image-space relevance value.
    """

    area = (
        block.width
        * block.height
    )

    # Y grows as the object moves lower in the image.
    y_factor = (
        block.y_center
        - MIN_VALID_Y
    ) / float(
        MAX_VALID_Y
        - MIN_VALID_Y
    )

    y_factor = clamp(
        y_factor,
        0.0,
        1.0
    )

    # Area factor is intentionally capped.
    area_factor = area / 1800.0

    area_factor = clamp(
        area_factor,
        0.0,
        1.0
    )

    return max(
        y_factor,
        area_factor
    )


# ================================================================
# PILLAR STEERING
# ================================================================

def pillar_steering(block):
    """
    Calculate obstacle steering.

    CRITICAL RULE:

        Signature determines SIDE.

        RED   -> RIGHT
        GREEN -> LEFT

    Camera X never changes that rule.

    X and apparent proximity only determine HOW STRONGLY Piolin
    steers toward the already selected side.
    """

    relevance = pillar_relevance(
        block
    )

    # ------------------------------------------------------------
    # RED -> PASS RIGHT
    # ------------------------------------------------------------

    if block.sig == SIG_RED:

        side = STEER_RIGHT

        desired_x = RED_TARGET_X

        color_name = "RED"

    # ------------------------------------------------------------
    # GREEN -> PASS LEFT
    # ------------------------------------------------------------

    else:

        side = STEER_LEFT

        desired_x = GREEN_TARGET_X

        color_name = "GREEN"

    # ------------------------------------------------------------
    # MAGNITUDE
    # ------------------------------------------------------------

    proximity_extra = (
        PILLAR_MAX_EXTRA
        * relevance
    )

    x_error = abs(
        desired_x
        - block.x_center
    )

    x_extra = (
        PIXY_X_GAIN
        * x_error
    )

    magnitude = (
        PILLAR_BASE_STEER
        + proximity_extra
        + x_extra
    )

    magnitude = clamp(
        magnitude,
        PILLAR_BASE_STEER,
        MAX_PILLAR_STEER
    )

    angle = (
        side
        * magnitude
    )

    print(
        color_name,
        "x:",
        block.x_center,
        "y:",
        block.y_center,
        "w:",
        block.width,
        "h:",
        block.height,
        "steer:",
        round(angle, 1)
    )

    return angle


# ================================================================
# TARGET MEMORY
# ================================================================

def remember_target(block, angle, now):
    """
    Store the most recent confirmed pillar command.
    """

    global last_target_signature
    global last_target_angle
    global last_target_time

    last_target_signature = (
        block.sig
    )

    last_target_angle = angle

    last_target_time = now


def remembered_target(now):
    """
    Keep the previous obstacle direction for a short time if Pixy
    briefly loses the pillar.

    Returns:
        remembered steering angle
        None if memory has expired
    """

    if last_target_signature is None:
        return None

    age = (
        now
        - last_target_time
    )

    if age > TARGET_MEMORY_MS:
        return None

    return last_target_angle


# ================================================================
# FLOOR SENSOR DEBUG
# ================================================================

def read_floor():
    """
    Read S4.

    V1 does not yet use S4 for the complete three-lap state machine,
    but keeping the sensor active allows course-mark testing and
    later expansion.
    """

    try:
        return COLOR_SENSOR.color()

    except Exception:
        return None


# ================================================================
# START
# ================================================================

def wait_for_start():
    """
    Wheels must be physically centered before starting.

    RIGHT button starts.
    DOWN button aborts.
    """

    EV3.screen.clear()

    EV3.screen.print(
        "ROUND 2 V1"
    )

    EV3.screen.print(
        "CENTER WHEELS"
    )

    EV3.screen.print(
        "RIGHT = START"
    )

    EV3.screen.print(
        "DOWN = STOP"
    )

    while Button.RIGHT in EV3.buttons.pressed():
        wait(20)

    while Button.RIGHT not in EV3.buttons.pressed():

        if Button.DOWN in EV3.buttons.pressed():
            return False

        wait(20)

    while Button.RIGHT in EV3.buttons.pressed():
        wait(20)

    return True


# ================================================================
# STOP
# ================================================================

def stop_robot():
    """
    Safe shutdown.
    """

    MOTOR_DRIVE.brake()

    try:
        set_steering(
            0,
            immediate=True
        )

        wait(100)

    except Exception:
        pass

    MOTOR_STEER.hold()


# ================================================================
# MAIN
# ================================================================
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

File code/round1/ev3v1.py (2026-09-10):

#!/usr/bin/env pybricks-micropython

# ================================================================
# PIOLIN - WRO FUTURE ENGINEERS 2026
# ROUND 1 / OPEN CHALLENGE - EV3 V1
#
# EARLY OPEN-ROUND PROTOTYPE
#
# Logic:
#   1. Drive straight.
#   2. Detect a floor color marking.
#   3. BLUE   -> turn LEFT.
#      ORANGE -> turn RIGHT.
#   4. Return steering to center.
#   5. Continue forward.
#   6. Count each accepted color event as one corner.
#   7. Stop after 12 accepted events.
#
# Hardware used in this version:
#   Motor A = rear propulsion
#   Motor B = steering
#   S4      = EV3 Color Sensor
#
# This early version does NOT use the ultrasonic sensors or gyro.
# It is preserved as part of Piolin's software evolution.
#
# IMPORTANT:
# This is a legacy/development version and does not represent
# the current Phase 4 Open Challenge controller.
# ================================================================


from pybricks.hubs import EV3Brick
from pybricks.ev3devices import Motor, ColorSensor
from pybricks.parameters import Port, Stop, Button, Color
from pybricks.tools import wait


# ================================================================
# HARDWARE
# ================================================================

ev3 = EV3Brick()

# Motor A = propulsion
drive = Motor(Port.A)

# Motor B = Ackermann steering
steering = Motor(Port.B)

# Downward-facing floor sensor
color_sensor = ColorSensor(Port.S4)


# ================================================================
# MAIN CALIBRATION PARAMETERS
# ================================================================

# Negative values correspond to forward motion on this Piolin build.
NORMAL_SPEED = -620

# Reduced speed while executing a corner.
TURN_SPEED = -420

# Steering motor target used during a color-triggered turn.
TURN_STEERING_ANGLE = 30

# Time spent maintaining the turning trajectory.
#
# This is one of the main calibration parameters in this early
# time-based corner implementation.
TURN_TIME_MS = 650

# Short forward movement after the turn to leave the color region.
POST_TURN_STRAIGHT_MS = 180

# Steering motor movement speed.
STEERING_SPEED = 700

# Change to -1 only if the physical steering direction is reversed.
STEER_DIRECTION = 1

# Three laps correspond to 12 corner events in this early model.
TOTAL_COUNTS = 12

# Number of equal readings required before accepting a color.
COLOR_CONFIRMATIONS = 2

# Number of neutral readings required before accepting a new line.
COLOR_RELEASE_CONFIRMATIONS = 3

# Main-loop delay.
LOOP_DELAY_MS = 10


# ================================================================
# STATE
# ================================================================

count = 0

candidate_color = None
candidate_count = 0

ready_for_new_color = True
release_count = 0


# ================================================================
# STEERING
# ================================================================

def center_steering():
    """
    Return Motor B to the steering-center reference.
    """

    steering.run_target(
        STEERING_SPEED,
        0,
        then=Stop.HOLD,
        wait=True
    )


# ================================================================
# FLOOR COLOR DETECTION
# ================================================================

def read_track_color():
    """
    Classify the current S4 reading.

    Returns:
        'BLUE'
        'ORANGE'
        None

    In this early prototype, the EV3 built-in color classifier
    was used directly.

    Depending on lighting, the orange floor marking could appear
    as RED, YELLOW, or BROWN to the EV3 sensor.
    """

    try:
        detected = color_sensor.color()

    except Exception:
        return None

    if detected == Color.BLUE:
        return 'BLUE'

    if detected in (
        Color.RED,
        Color.YELLOW,
        Color.BROWN
    ):
        return 'ORANGE'

    return None


# ================================================================
# EARLY COLOR-TRIGGERED CORNER LOGIC
# ================================================================

def turn_for_color(detected_color):
    """
    Execute the early time-based turn.

    BLUE:
        turn LEFT

    ORANGE:
        turn RIGHT

    This version uses the floor color itself to determine the turn
    direction and uses time to determine how long the corner lasts.
    """

    if detected_color == 'BLUE':

        target = (
            -TURN_STEERING_ANGLE
            * STEER_DIRECTION
        )

        print('BLUE -> LEFT')

    else:

        target = (
            TURN_STEERING_ANGLE
            * STEER_DIRECTION
        )

        print('ORANGE -> RIGHT')

    # Move Motor B to the requested steering angle.
    steering.run_target(
        STEERING_SPEED,
        target,
        then=Stop.HOLD,
        wait=True
    )

    # Move through the corner.
    drive.run(TURN_SPEED)

    wait(TURN_TIME_MS)

    # Return steering to center.
    center_steering()

    # Leave the color marking before normal detection resumes.
    drive.run(NORMAL_SPEED)

    wait(POST_TURN_STRAIGHT_MS)


# ================================================================
# FINISH
# ================================================================

def stop_finished():
    """
    Stop Piolin after completing the 12 accepted events.
    """

    drive.hold()

    center_steering()

    ev3.screen.clear()

    ev3.screen.draw_text(
        30,
        45,
        'FINISHED 12/12'
    )

    try:
        ev3.speaker.beep(
            1200,
            300
        )

    except Exception:
        pass

    print('FINISHED 12/12')


# ================================================================
# START CONTROL
# ================================================================

def wait_for_start():
    """
    Wait until the EV3 center button is pressed.
    """

    ev3.screen.clear()

    ev3.screen.draw_text(
        25,
        45,
        'PRESS CENTER'
    )

    # Wait for any previous press to be released.
    while Button.CENTER in ev3.buttons.pressed():
        wait(20)

    # Wait for start press.
    while Button.CENTER not in ev3.buttons.pressed():
        wait(20)

    # Wait for release.
    while Button.CENTER in ev3.buttons.pressed():
        wait(20)


# ================================================================
# INITIALIZATION
# ================================================================

# The steering wheels must be physically centered before startup.
steering.reset_angle(0)

center_steering()

wait_for_start()

ev3.screen.clear()

ev3.screen.draw_text(
    35,
    45,
    'COUNT 0/12'
)

drive.run(NORMAL_SPEED)


# ================================================================
# MAIN LOOP
# ================================================================
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

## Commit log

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2026-06-18 Simplify engineering framework description
    Added better explanation from the engineering framework description.
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2026-06-18 Add hardware components overview to documentation
    Added detailed overview of hardware components including sensors, motors, and controllers used in the robot. Each component is described with specifications and functionalities to enhance understandi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
2026-06-18 Add wiring diagram documentation for hardware I/O
    This document outlines the current hardware I/O register and electrical interface for the system, detailing the components and their functions.
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2026-07-21 Add README for electrical schematics and diagrams
    Added detailed documentation for electrical schematics and circuit diagrams, including images and descriptions for the EV3 interface, PiolínTech system architecture, and physical circuit implementati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
2026-07-21 Create 02_VProcessing.md with mermaid diagram
    Add a mermaid diagram for visual processing flow.
2026-07-21 Enhance documentation on mobility and design analysis
    Expanded the document to include detailed sections on mobility framework, steering geometry, powertrain analysis, and mechanical iterations for the Piolín robot. Added mathematical models and design 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
2026-07-21 Enhance SWArchitecture documentation with algorithms
    Added detailed explanations and Python code snippets for the robot's steering and line detection algorithms, including the odometry-backed line detection system and the finite state machine phases.
2026-07-21 Document performance testing and control loop analysis
    Added detailed sections on performance testing, spatial sensing reliability, and kinematic control loop analysis, including mathematical formulations and benchmark data.
2026-08-16 Revise README for architecture and component updates
    Updated the README to reflect changes in the robot's architecture, including the transition from LEGO Mindstorms to Arduino Mega and the integration of HuskyLens for vision processing. Added details 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
2026-08-16 Revise hardware documentation for configuration updates
    Updated hardware documentation to reflect changes in configurations and components, including the transition from Raspberry Pi 5 to Arduino Mega 2560, and modifications in sensor polling and power co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
2026-08-16 Replace Raspberry Pi 5 with Arduino Mega 2560 for stability
    Migrated from Raspberry Pi 5 to Arduino Mega 2560 to resolve power delivery issues during full load testing, ensuring stable performance for steering actuators.
2026-09-02 Revise project overview and technical specifications
    Expanded project overview for Piolín, detailing objectives, components, and operational workflow. Updated sections on navigation sensors, electronic architecture, and challenge-specific usage.
2026-09-02 Revise Power & Sensor Architecture documentation
    Updated the Power & Sensor Architecture documentation for Piolín, including detailed descriptions of the final configuration, sensor responsibilities, and engineering principles. Enhanced clarity and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
2026-09-02 Document final ultrasonic sensor architecture for Piolín
    This document outlines the final ultrasonic sensor architecture for Piolín, detailing the roles and configurations of three LEGO ultrasonic sensors used for navigation and safety. It includes specifications, mounting details, and the separation of responsibilities between the sensors for effective track navigation and collision avoidance.
2026-09-02 Modify ultrasonic sensor description for EV3 Port S1
    Updated the description of the ultrasonic sensor connected to EV3 Port S1 to specify its function for parking.
2026-09-02 Update sensor information in HComponents documentation
    Replaced unused sensor port with a front distance sensor to measure distance to the front-side track.
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2026-09-04 Enhance EV3 documentation with detailed architecture
    Expanded documentation on the LEGO Mindstorms EV3 Intelligent Brick, detailing its role, port assignments, motor control, sensor acquisition, navigation logic, and integration with the vision subsyst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
2026-09-04 Add detailed documentation for motors and actuation system
    Document the architecture and functionality of Piolín's motor and actuation system, detailing the roles of the drive and steering motors, their mechanical connections, and the implications for vehicl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
2026-09-04 Enhance Color Sensor documentation
    Expanded documentation on the LEGO Color Sensor's functionality, configuration, and integration within Piolín's navigation system, including details on its role in determining direction and tracking 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
2026-09-04 Add detailed documentation for HuskyLens integration
    Document the functionality and integration of the HuskyLens vision sensor in Piolín for obstacle detection and navigation.
2026-09-04 Document battery role in Piolín's energy architecture
    Added comprehensive documentation on the battery and its role in Piolín's energy architecture, detailing its influence on propulsion, steering, sensing, and overall robot behavior.
2026-09-04 Add legacy documentation notice for historical context
    Added a comprehensive legacy documentation notice explaining the purpose and importance of the legacy files. Emphasized the distinction between legacy and current documentation, and provided guidance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
2026-09-05 Revise legacy gyroscope navigation documentation
    Updated legacy documentation to clarify the historical role of the gyroscope in Piolín's navigation system and its removal from the current architecture. Added warnings about the legacy nature of the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
